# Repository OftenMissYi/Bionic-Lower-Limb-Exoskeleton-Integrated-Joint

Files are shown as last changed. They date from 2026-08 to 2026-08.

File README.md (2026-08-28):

# 🦿 Bionic Lower-Limb Exoskeleton Integrated Joint

Design and performance analysis of an integrated joint drive unit for a bionic lower-limb exoskeleton, developed as my undergraduate graduation project.

The project focused on the mechanical design and integration of a compact knee joint actuator, combining a high-power-density BLDC motor, planetary gearbox and torque sensing into an integrated drive unit. The designed actuator was also integrated into an existing lower-limb exoskeleton structure through an in-situ replacement approach.

## 🔧 Key Contributions

* Designed an integrated knee joint drive unit for a bionic lower-limb exoskeleton
* Developed a single-stage NGW planetary gearbox with a reduction ratio of 3.75
* Performed motor selection and transmission parameter design
* Designed the integrated mechanical structure, including the housing, shaft system, output interface and supporting components
* Integrated a torque sensor into the drive transmission chain
* Designed the drive unit for direct integration with an existing exoskeleton structure
* Performed structural and performance analysis using finite element and multibody dynamics simulation
* Evaluated stress, deformation, output speed, motor torque and transmission error under rated and peak load conditions
* Proposed a hierarchical control architecture combining gait-phase recognition, impedance control and ADRC-based trajectory tracking

## ⚙️ Design Overview

The actuator follows a quasi-direct-drive (QDD) concept based on a high-power-density BLDC motor and a compact planetary gearbox.

The main design targets included:

* Peak output torque: ≥ 55 N·m
* Rated output torque: 21 N·m
* Joint operating range: 0–160°
* Planetary gearbox ratio: 3.75
* Target transmission efficiency: ≥ 90%

The integrated design combines the drive, transmission and torque sensing functions into a compact coaxial mechanical system.

## 🧮 Simulation & Analysis

The designed drive unit was evaluated through both finite element analysis and multibody dynamics simulation.

### Finite Element Analysis

Structural simulations were used to evaluate the planetary gearbox and integrated mechanical structure under representative loading conditions, including stress, strain and deformation.

### ADAMS Multibody Dynamics

A multibody dynamics model was developed to evaluate the dynamic behaviour of the planetary transmission under changing load conditions.

The analysis included:

* Output angular velocity
* Motor driving torque
* Gear meshing forces
* Transmission error
* Dynamic response under rated and peak torque loading

The simulation results were used to verify the feasibility of the mechanical design and its ability to meet the target performance requirements.

## 🧠 Control Strategy

A hierarchical control concept was developed for the integrated joint drive system, consisting of gait-phase recognition, dual-mode control and low-level motor control.

The proposed strategy combines adaptive impedance control during the support phase with ADRC-based trajectory tracking during the swing phase.

The control architecture was developed at the theoretical/software level as part of the project. Physical prototype and hardware-in-the-loop validation were outside the completed project scope.

## 📁 Repository Structure

```text
Bionic-Lower-Limb-Exoskeleton/
├── CAD/
│   ├── Drive_Unit/
│   ├── Planetary_Gearbox/
│   └── Exoskeleton_Integration/
│
├── Simulation/
│   ├── ANSYS/
│   └── ADAMS/
│
└── docs/
    ├── project_report_excerpt.pdf
    └── defense_presentation.pdf
```

The repository contains the original CAD and simulation project files together with selected documentation from the undergraduate thesis and defense presentation.

Some CAD and simulation files retain their original Chinese filenames and may require the corresponding commercial software to open.

## 🛠️ Technologies

`SolidWorks` · `ANSYS Workbench` · `MSC Adams` · `Planetary Gearbox` · `Mechanical Design` · `Finite Element Analysis` · `Multibody Dynamics` · `Robot Actuation`

## ⚠️ Project Scope & Limitations

This project focused primarily on the mechanical design, integration and simulation-based evaluation of a single knee joint drive unit.

The project did not include:

* Physical prototype fabrication
* Experimental validation on a wearable exoskeleton
* Hardware-in-the-loop testing
* Multi-joint gait experiments

The repository therefore represents the engineering design and simulation stage of the project rather than a fully experimentally validated exoskeleton system.

## 📚 Documentation

Selected pages from the original undergraduate thesis are provided in `docs/` together with the complete defense presentation for additional technical background and design details.

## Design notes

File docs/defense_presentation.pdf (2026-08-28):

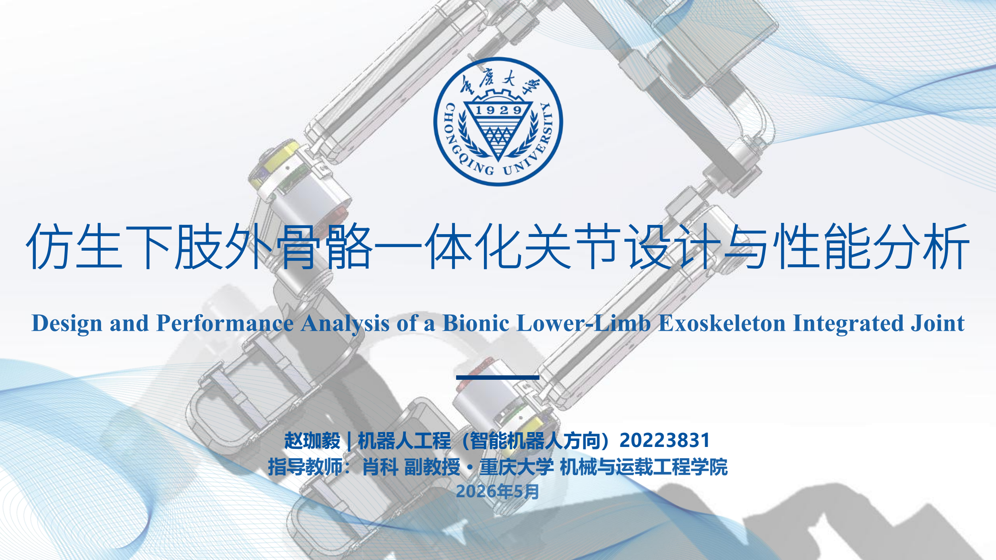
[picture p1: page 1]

# 仿生下肢外骨骼一体化关节设计与性能分析

# Design and Performance Analysis of a Bionic Lower-Limb Exoskeleton Integrated Joint

## 赵珈毅 | 机器人工程（智能机器人方向）20223831 指导教师：肖科 副教授 · 重庆大学 机械与运载工程学院

2026年5月

# 汇报提纲

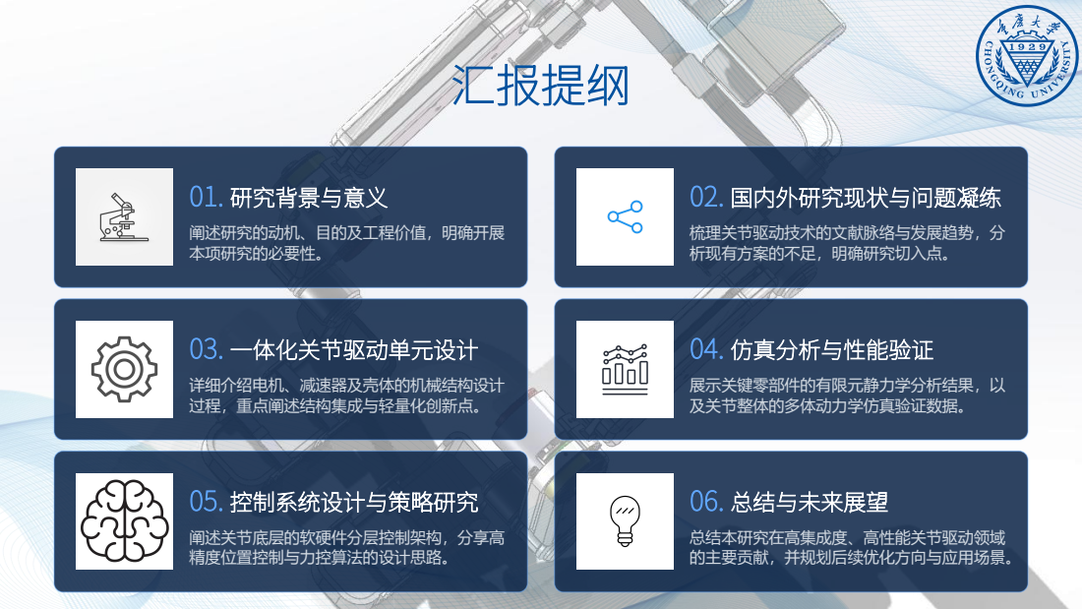
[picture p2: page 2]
01. 研究背景与意义; 02. 国内外研究现状与问题凝练; 梳理关节驱动技术的文献脉络与发展趋势，分 析现有方案的不足，明确研究切入点。; 详细介绍电机、减速器及壳体的机械结构设计 过程，重点阐述结构集成与轻量化创新点。; 04. 仿真分析与性能验证; 展示关键零部件的有限元静力学分析结果，以 及关节整体的多体动力学仿真验证数据。; 05. 控制系统设计与策略研究; 阐述关节底层的软硬件分层控制架构，分享高 精度位置控制与力控算法的设计思路。; 06. 总结与未来展望; 总结本研究在高集成度、高性能关节驱动领域 的主要贡献，并规划后续优化方向与应用场景。

阐述研究的动机、目的及工程价值，明确开展
本项研究的必要性。
03. 一体化关节驱动单元设计

# 研究背景与意义 —— 问题的提出

# 为什么要设计一体化关节驱动器？

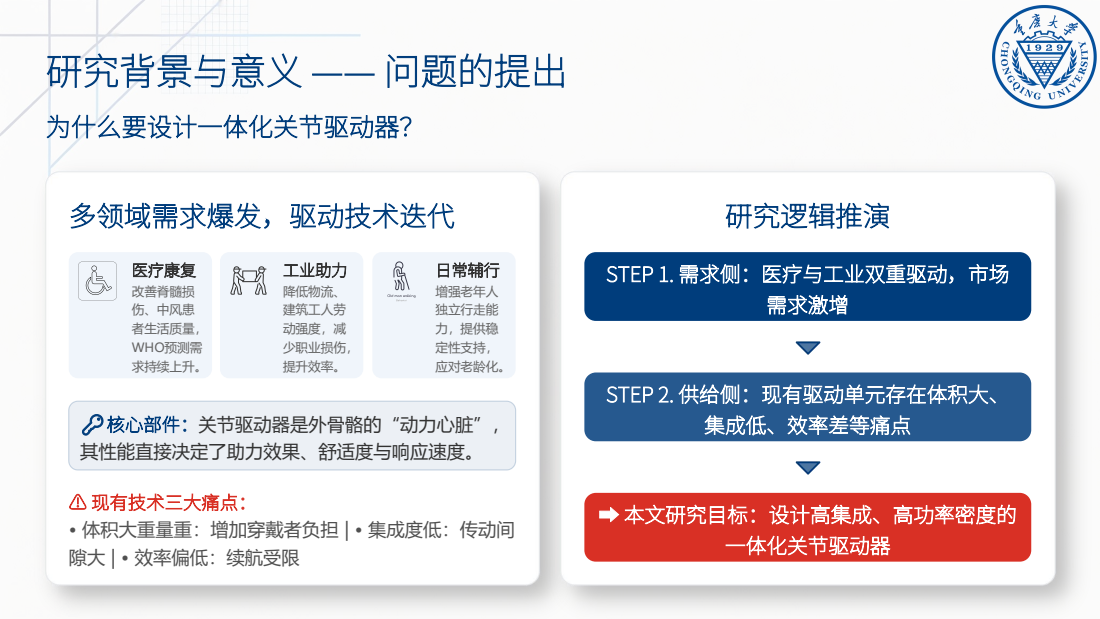
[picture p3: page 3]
多领域需求爆发，驱动技术迭代; 医疗康复; 求持续上升。; 工业助力; 降低物流、 建筑工人劳 动强度，减 少职业损伤，; 提升效率。; 日常辅行; 增强老年人 独立行走能 力，提供稳 定性支持，

研究逻辑推演
STEP 1. 需求侧：医疗与工业双重驱动，市场
需求激增
STEP 2. 供给侧：现有驱动单元存在体积大、
集成低、效率差等痛点
➡ 本文研究目标：设计高集成、高功率密度的
一体化关节驱动器

改善脊髓损
伤、中风患
者生活质量， WHO预测需
应对老龄化。  核心部件：关节驱动器是外骨骼的“动力心脏”，

其性能直接决定了助力效果、舒适度与响应速度。
⚠ 现有技术三大痛点：
• 体积大重量重：增加穿戴者负担 | • 集成度低：传动间
隙大 | • 效率偏低：续航受限

# 研究背景与意义 —— 研究目标与工程价值

## 核心目标：提出并设计一种“驱动-传动-检测”一体化、高功率密度的仿生下肢

## 外骨骼膝关节驱动器，旨在解决现有驱动单元体积大、集成度低、效率不高等关 键问题，为外骨骼系统的性能提升提供核心动力方案。

# ▍ 工程价值

- 准直接驱动 (QDD) 架构：采用“无刷直流电机 + 单级
行星减速器”的复合方案，兼顾输出大扭矩、高传动效率和良 好的背驱特性。
- 力矩传感器内嵌集成：将多维力矩传感器深度融合进传 动链，实现“驱动-传动-检测”一体化闭环控制，显著提升系 统的控制精度与动态响应速度。
- 原位替换设计：标准化机械与电气接口设计，可直接集成
到现有主流外骨骼骨架中，具备极强的工程通用性。 | ▍ 应用前景
| · 医疗康复领域：可应用于康复机器人，为脊髓损伤、脑卒 中患者提供高精度、高舒适度的康复训练与辅助步行。
| · 工业助力领域：适配工业外骨骼，在物流搬运、汽车制造 等体力消耗大的场景中，为工人提供有效负重助力，降低职业 损伤风险。
| · 日常辅助领域：为高龄老人或行动不便人群提供行走稳定 性支持，帮助他们独立完成日常生活活动，提升生活质量。

# 二、国内外研究现状 —— 四个维度的文献脉络

# 01 运动机理与生物力学

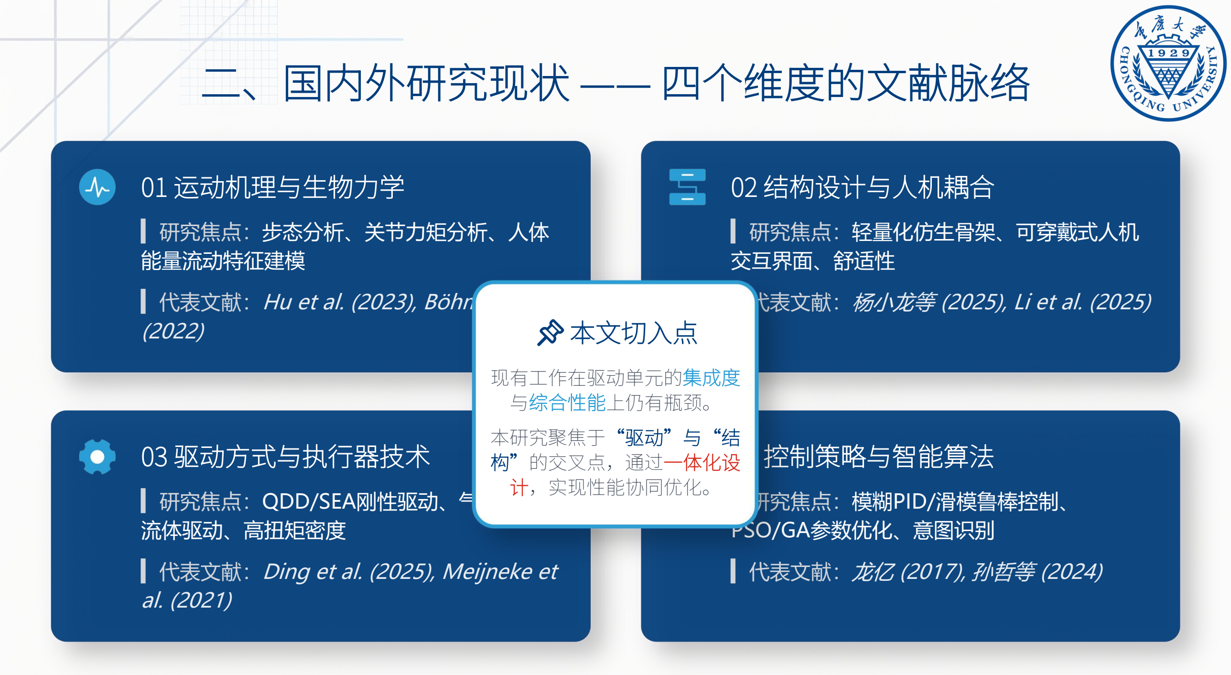
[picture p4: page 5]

▍ 研究焦点：步态分析、关节力矩分析、人体
能量流动特征建模
▍ 代表文献：Hu et al. (2023), Böhme et al. (2022)

# 02 结构设计与人机耦合

▍ 研究焦点：轻量化仿生骨架、可穿戴式人机
交互界面、舒适性
▍ 代表文献：杨小龙等 (2025), Li et al. (2025)

# 03 驱动方式与执行器技术

▍ 研究焦点：QDD/SEA刚性驱动、气动/柔性
流体驱动、高扭矩密度
▍ 代表文献：Ding et al. (2025), Meijneke et al. (2021)

# 04 控制策略与智能算法

▍ 研究焦点：模糊PID/滑模鲁棒控制、
PSO/GA参数优化、意图识别
▍ 代表文献：龙亿 (2017), 孙哲等 (2024)

# 本文切入点

# 现有工作在驱动单元的集成度 与综合性能上仍有瓶颈。 本研究聚焦于“驱动”与“结 构”的交叉点，通过一体化设 计，实现性能协同优化。

# 二、国内外研究现状 —— 问题凝练与本文定位

驱动方式 | 输出扭矩 | 体积 / 重量 | 背驱性 | 集成度 | 适用场景
电机直驱 | 小 | 小 | 极好 | 极高 | 低负载、高响应关节
丝杠驱动 | 大 | 大 | 差 | 低 | 高负载、低速、固定场景
谐波减速 | 大 | 中 | 差 | 中 | 工业机器人、高精度定位
行星齿轮 (QDD) | 中 - 大 | 小 | 好 | 高 | ← 本文选择 一体化集成

将电机、减速器、传感器进行同轴一体化
设计，在保证功能完备性的同时最大化空
间利用率，提升系统整体紧凑性。 | 准直接驱动

采用行星齿轮减速器(QDD)方案，在大扭
矩输出与良好背驱性之间取得最佳平衡，
满足动态响应与负载能力的双重需求。 | 分层控制策略

设计包含“模式识别层-双模态切换层-底
层伺服控制层”的三层架构，实现从高层
意图到底层执行的精准、稳定映射。

# 二、国内外研究现状 —— 问题凝练与本文定位

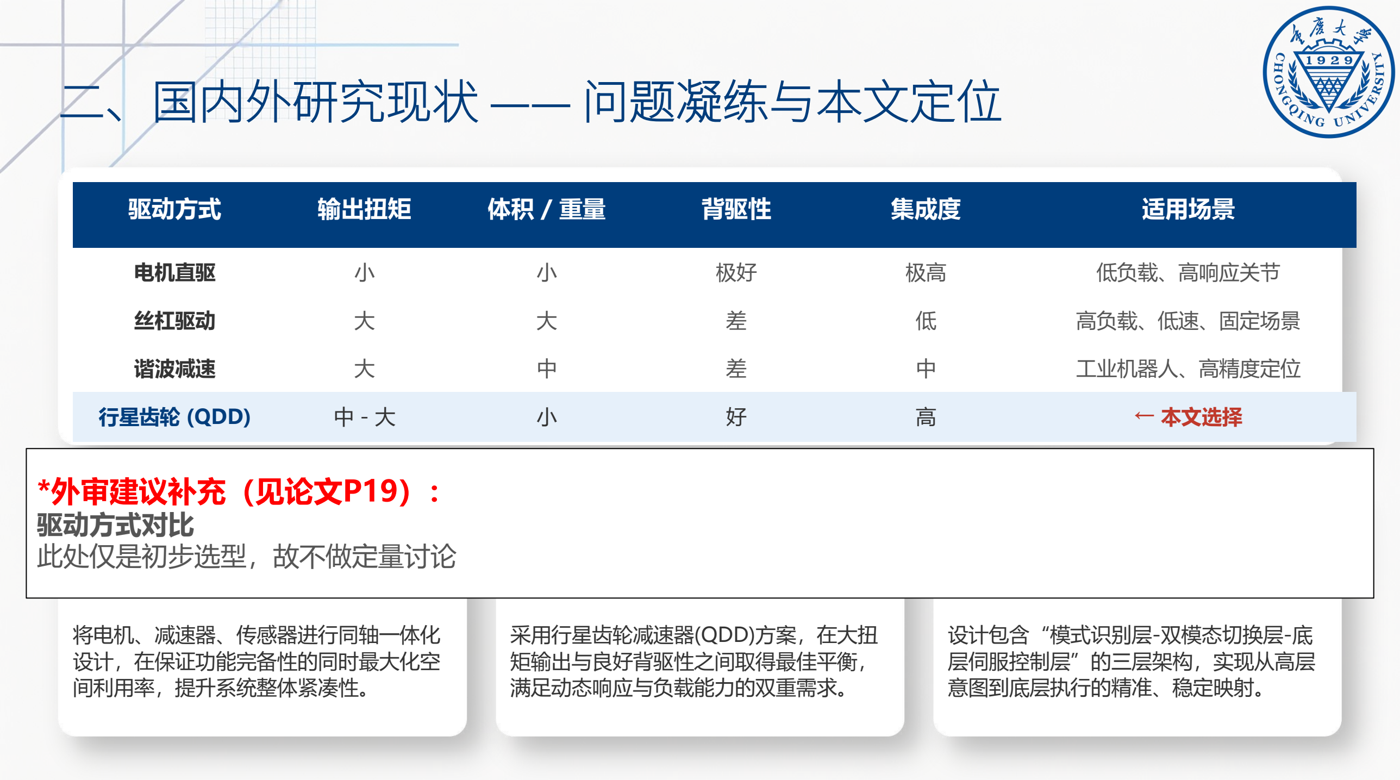
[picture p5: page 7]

驱动方式 | 输出扭矩 | 体积 / 重量 | 背驱性 | 集成度 | 适用场景
电机直驱 | 小 | 小 | 极好 | 极高 | 低负载、高响应关节
丝杠驱动 | 大 | 大 | 差 | 低 | 高负载、低速、固定场景
谐波减速 | 大 | 中 | 差 | 中 | 工业机器人、高精度定位
行星齿轮 (QDD) | 中 - 大 | 小 | 好 | 高 | ← 本文选择 一体化集成

将电机、减速器、传感器进行同轴一体化
设计，在保证功能完备性的同时最大化空
间利用率，提升系统整体紧凑性。 | 准直接驱动

采用行星齿轮减速器(QDD)方案，在大扭
矩输出与良好背驱性之间取得最佳平衡，
满足动态响应与负载能力的双重需求。 | 分层控制策略

设计包含“模式识别层-双模态切换层-底
层伺服控制层”的三层架构，实现从高层
意图到底层执行的精准、稳定映射。

## *外审建议补充（见论文P19）：

## 驱动方式对比

### 此处仅是初步选型，故不做定量讨论

# 三、一体化关节设计 —— 人体步态与设计指标

# ▌ 人体步态周期关键信息

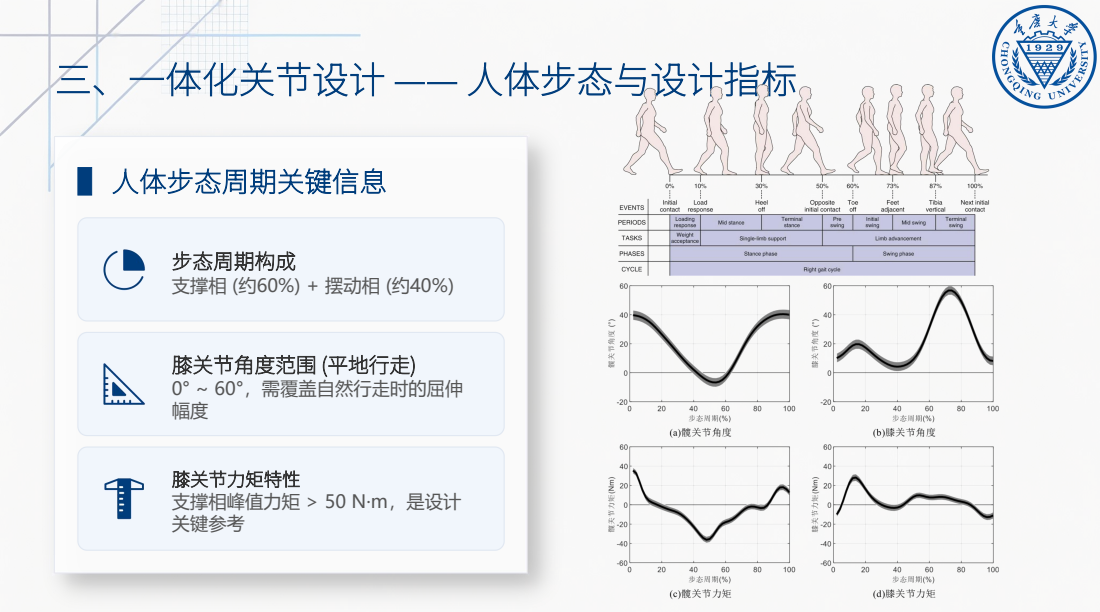
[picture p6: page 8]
步态周期构成; 支撑相 (约60%) + 摆动相 (约40%) 膝关节角度范围 (平地行走); 0° ~ 60°，需覆盖自然行走时的屈伸 幅度 膝关节力矩特性; 支撑相峰值力矩 > 50 N·m，是设计 关键参考

# 三、一体化关节设计 —— 人体步态与设计指标

# ▌ 膝关节驱动单元设计指标

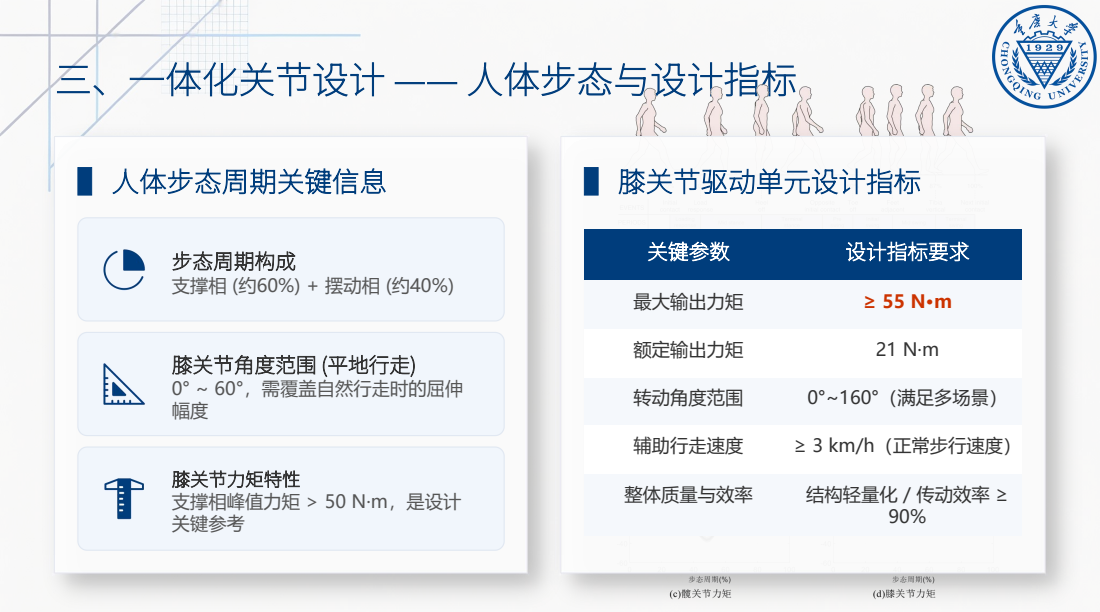
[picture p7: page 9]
▌ 人体步态周期关键信息; 步态周期构成; 支撑相 (约60%) + 摆动相 (约40%) 膝关节角度范围 (平地行走); 0° ~ 60°，需覆盖自然行走时的屈伸 幅度 膝关节力矩特性; 支撑相峰值力矩 > 50 N·m，是设计 关键参考

关键参数 | 设计指标要求

最大输出力矩 | ≥ 55 N·m

额定输出力矩 | 21 N·m

转动角度范围 | 0°~160°（满足多场景）

辅助行走速度 | ≥ 3 km/h（正常步行速度）

整体质量与效率 | 结构轻量化 / 传动效率 ≥ 90%

# 三、一体化关节设计 —— 总体方案与驱动选型

# 总体架构：准直接驱动 (QDD) 理念

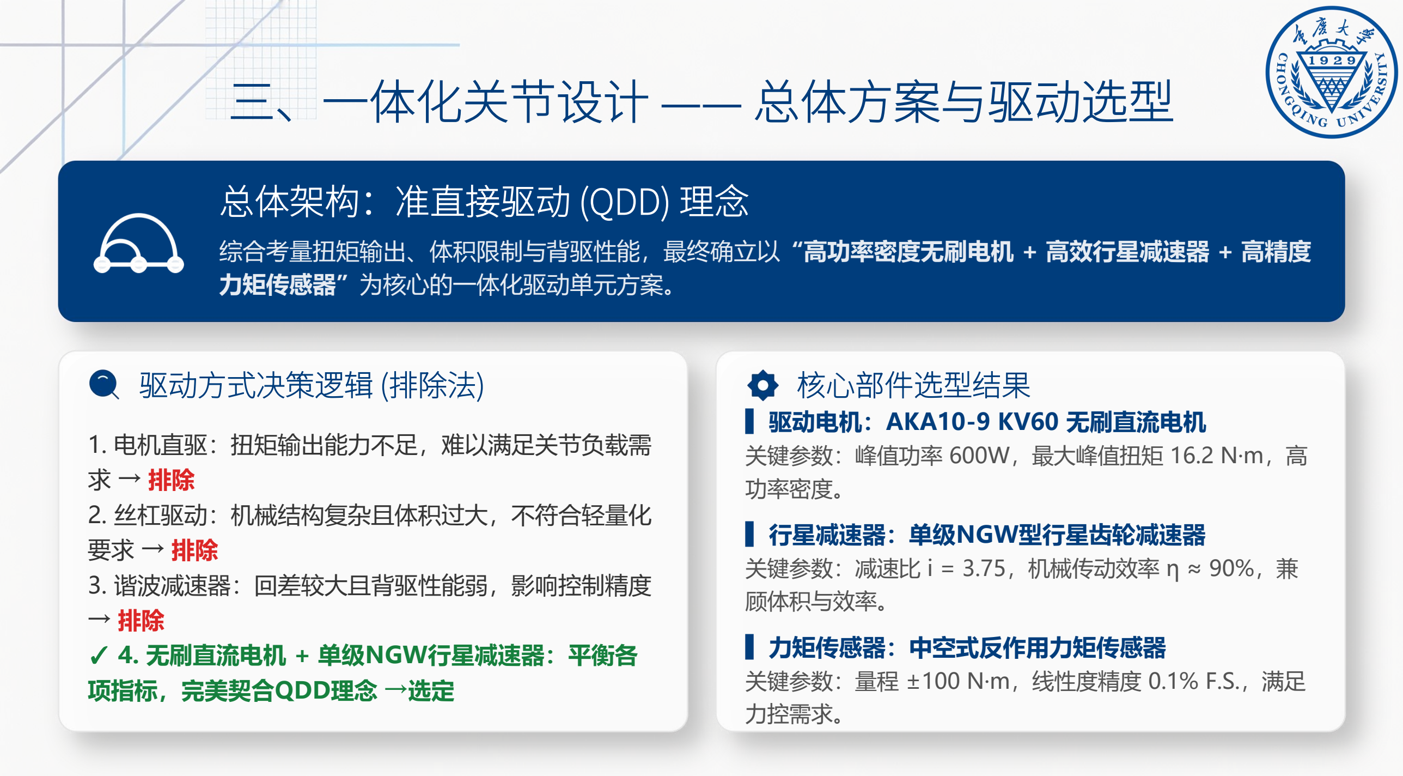
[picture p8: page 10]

综合考量扭矩输出、体积限制与背驱性能，最终确立以“高功率密度无刷电机 + 高效行星减速器 + 高精度 力矩传感器”为核心的一体化驱动单元方案。 驱动方式决策逻辑 (排除法)

1. 电机直驱：扭矩输出能力不足，难以满足关节负载需 求 → 排除
2. 丝杠驱动：机械结构复杂且体积过大，不符合轻量化 要求 → 排除
3. 谐波减速器：回差较大且背驱性能弱，影响控制精度 → 排除
✓ 4. 无刷直流电机 + 单级NGW行星减速器：平衡各 项指标，完美契合QDD理念 →选定

# 核心部件选型结果

▌ 驱动电机：AKA10-9 KV60 无刷直流电机 关键参数：峰值功率 600W，最大峰值扭矩 16.2 N·m，高 功率密度。
▌ 行星减速器：单级NGW型行星齿轮减速器
关键参数：减速比 i = 3.75，机械传动效率 η ≈ 90%，兼 顾体积与效率。
▌ 力矩传感器：中空式反作用力矩传感器
关键参数：量程 ±100 N·m，线性度精度 0.1% F.S.，满足 力控需求。

# 三、一体化关节设计 —— 总体方案与驱动选型

# 总体架构：准直接驱动 (QDD) 理念

综合考量扭矩输出、体积限制与背驱性能，最终确立以“高功率密度无刷电机 + 高效行星减速器 + 高精度 力矩传感器”为核心的一体化驱动单元方案。 驱动方式决策逻辑 (排除法)

1. 电机直驱：扭矩输出能力不足，难以满足关节负载需 求 → 排除
2. 丝杠驱动：机械结构复杂且体积过大，不符合轻量化 要求 → 排除
3. 谐波减速器：回差较大且背驱性能弱，影响控制精度 → 排除
✓ 4. 无刷直流电机 + 单级NGW行星减速器：平衡各 项指标，完美契合QDD理念 →选定

# 核心部件选型结果

▌ 驱动电机：AKA10-9 KV60 无刷直流电机 关键参数：峰值功率 600W，最大峰值扭矩 16.2 N·m，高 功率密度。
▌ 行星减速器：单级NGW型行星齿轮减速器
关键参数：减速比 i = 3.75，机械传动效率 η ≈ 90%，兼 顾体积与效率。
▌ 力矩传感器：中空式反作用力矩传感器
关键参数：量程 ±100 N·m，线性度精度 0.1% F.S.，满足 力控需求。

# 三、一体化关节设计 —— 行星减速器核心参数

齿根弯曲应力 <200 MPa ✓ 强度安全

# 三、一体化关节设计 —— 行星减速器核心参数

## *外审建议补充（见论文P23）：

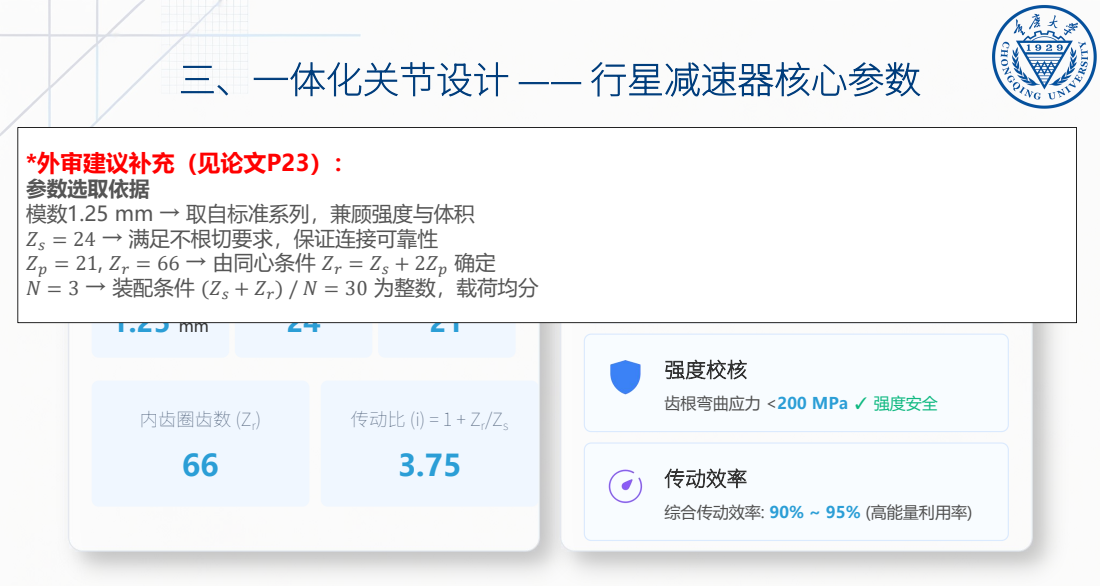
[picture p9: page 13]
核心设计参数; 太阳轮齿数 (Zs) 24; 行星轮齿数 (Zp; 内齿圈齿数 (Zr) 66; 传动比 (i) = 1 + Zr/Zs 3.75; 性能校核 理论输出扭矩; ≈60.75 N·m (目标: 55 N·m) ✓ 满足要求 强度校核; 传动效率; 综合传动效率: 90% ~ 95% (高能量利用率);  = 21,  = 66 → 由同心条件  =  + 2 确定  = 3 → 装配条件 ( + ) /  = 30 为整数，载荷均分

参数选取依据
 = 24 → 满足不根切要求，保证连接可靠性
模数1.25 mm → 取自标准系列，兼顾强度与体积

齿根弯曲应力 <200 MPa ✓ 强度安全

# 三、一体化关节设计 —— 行星减速器核心参数

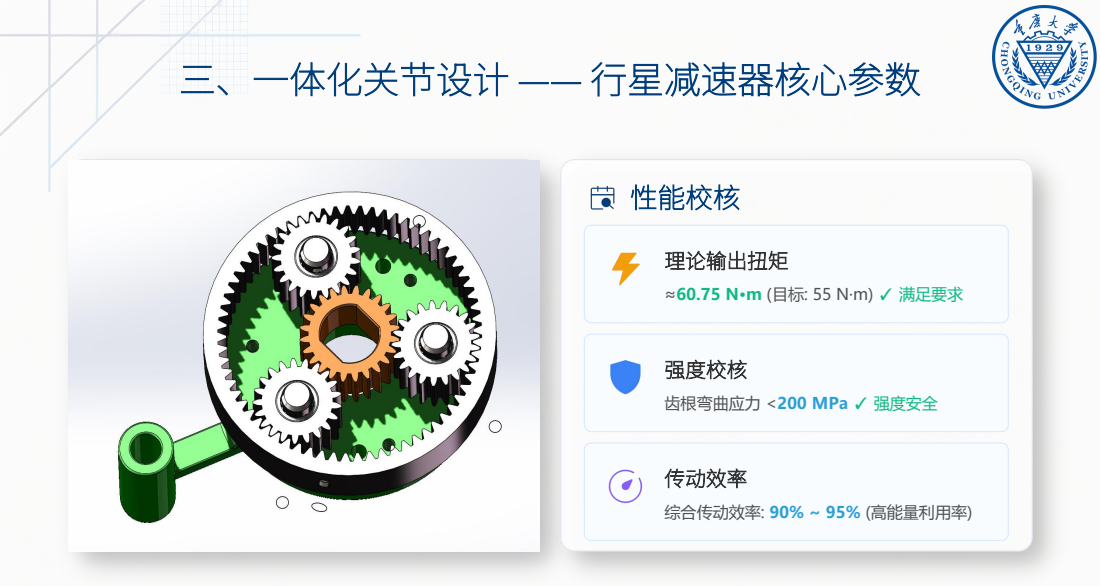
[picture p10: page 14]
核心设计参数; 太阳轮齿数 (Zs) 24; 行星轮齿数 (Zp) 21; 内齿圈齿数 (Zr) 66; 传动比 (i) = 1 + Zr/Zs 3.75; 性能校核 理论输出扭矩; ≈60.75 N·m (目标: 55 N·m) ✓ 满足要求 强度校核; 传动效率; 综合传动效率: 90% ~ 95% (高能量利用率)

齿根弯曲应力 <200 MPa ✓ 强度安全

# 三、一体化关节设计 —— 一体化结构创新

# 01. 一体化长轴设计

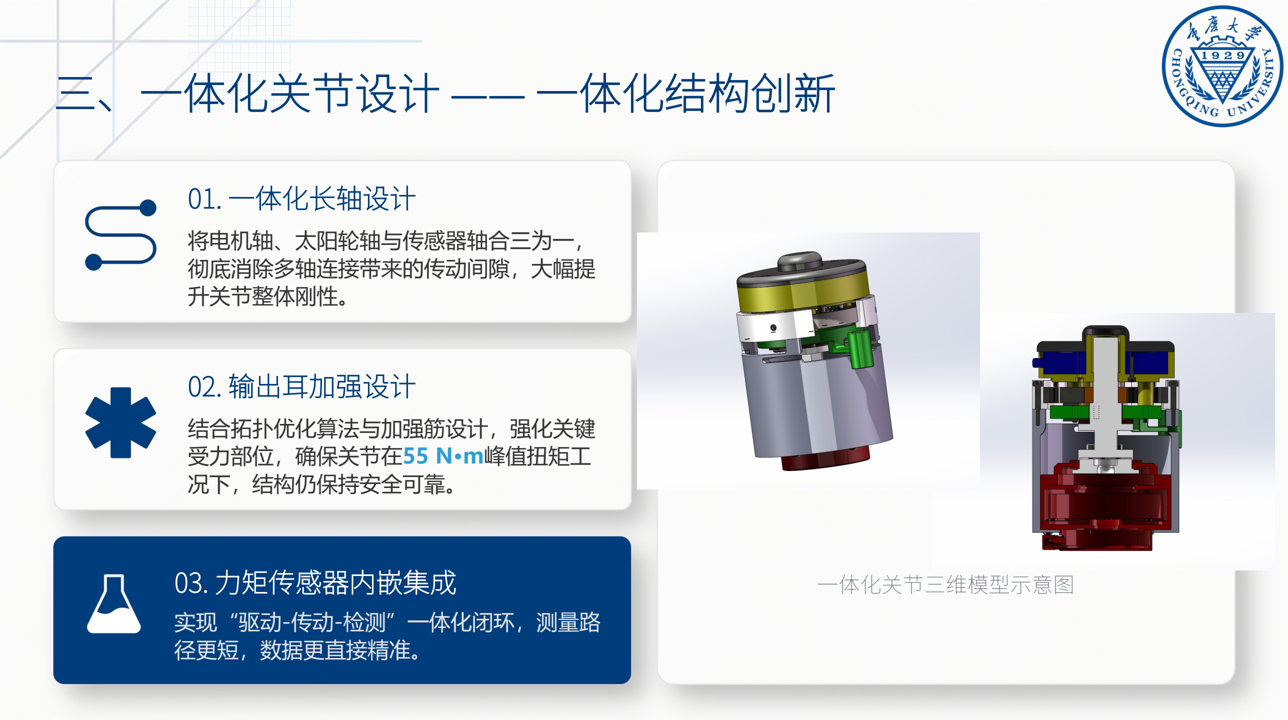
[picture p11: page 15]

将电机轴、太阳轮轴与传感器轴合三为一，
彻底消除多轴连接带来的传动间隙，大幅提
升关节整体刚性。

# 02. 输出耳加强设计

结合拓扑优化算法与加强筋设计，强化关键
受力部位，确保关节在55 N·m峰值扭矩工
况下，结构仍保持安全可靠。

# 03. 力矩传感器内嵌集成

实现“驱动-传动-检测”一体化闭环，测量路
径更短，数据更直接精准。

# 一体化关节三维模型示意图

# 四、仿真分析 —— 有限元应力与变形

# 齿面接触应力分析

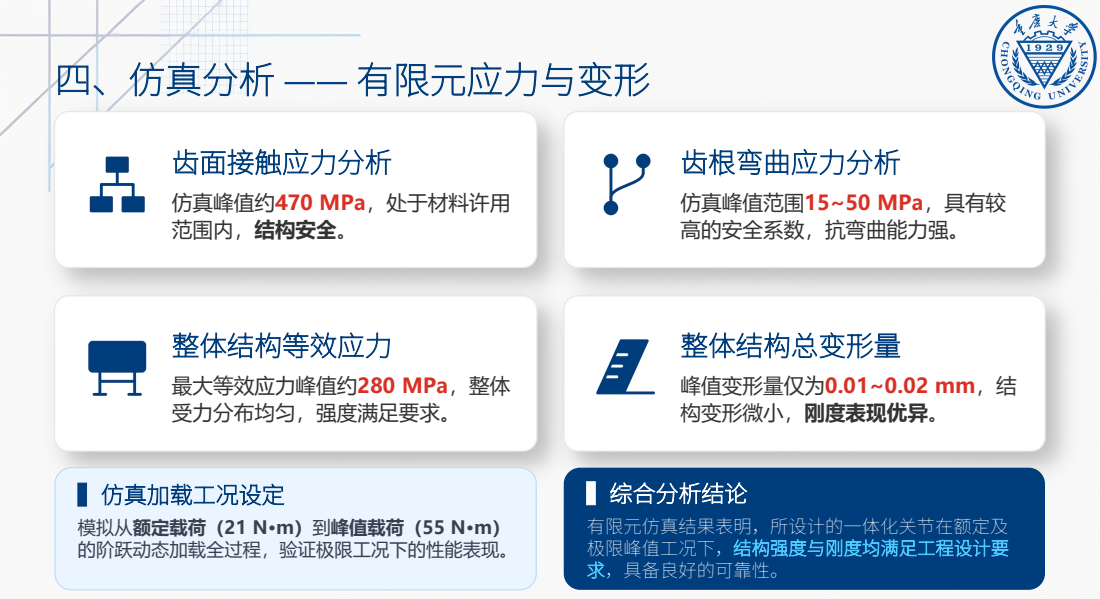
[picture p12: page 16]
范围内，结构安全。; 齿根弯曲应力分析; 仿真峰值范围15~50 MPa，具有较; 最大等效应力峰值约280 MPa，整体; 受力分布均匀，强度满足要求。; 整体结构总变形量; 峰值变形量仅为0.01~0.02 mm，结; 模拟从额定载荷（21 N·m）到峰值载荷（55 N·m）; 的阶跃动态加载全过程，验证极限工况下的性能表现。; ▍综合分析结论; 有限元仿真结果表明，所设计的一体化关节在额定及 极限峰值工况下，结构强度与刚度均满足工程设计要 求，具备良好的可靠性。

仿真峰值约470 MPa，处于材料许用
高的安全系数，抗弯曲能力强。 整体结构等效应力

构变形微小，刚度表现优异。 ▍仿真加载工况设定

# 四、仿真分析 —— 有限元应力与变形

# 齿面接触应力分析

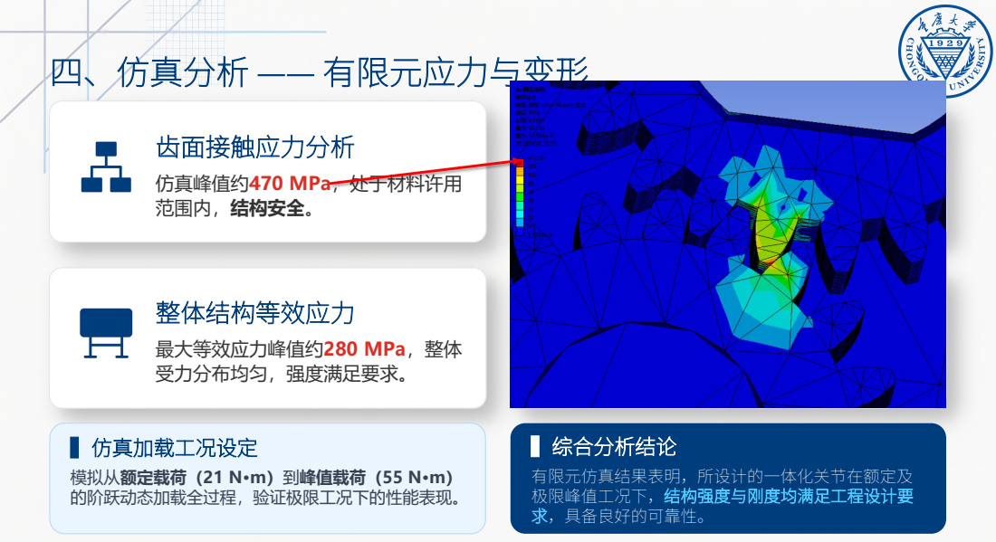
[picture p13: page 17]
范围内，结构安全。; 齿根弯曲应力分析; 仿真峰值范围15~50 MPa，具有较; 最大等效应力峰值约280 MPa，整体; 受力分布均匀，强度满足要求。; 整体结构总变形量; 峰值变形量仅为0.01~0.02 mm，结; 模拟从额定载荷（21 N·m）到峰值载荷（55 N·m）; 的阶跃动态加载全过程，验证极限工况下的性能表现。; ▍综合分析结论; 有限元仿真结果表明，所设计的一体化关节在额定及 极限峰值工况下，结构强度与刚度均满足工程设计要 求，具备良好的可靠性。

仿真峰值约470 MPa，处于材料许用
高的安全系数，抗弯曲能力强。 整体结构等效应力

构变形微小，刚度表现优异。 ▍仿真加载工况设定

# 四、仿真分析 —— 有限元应力与变形

# 齿面接触应力分析

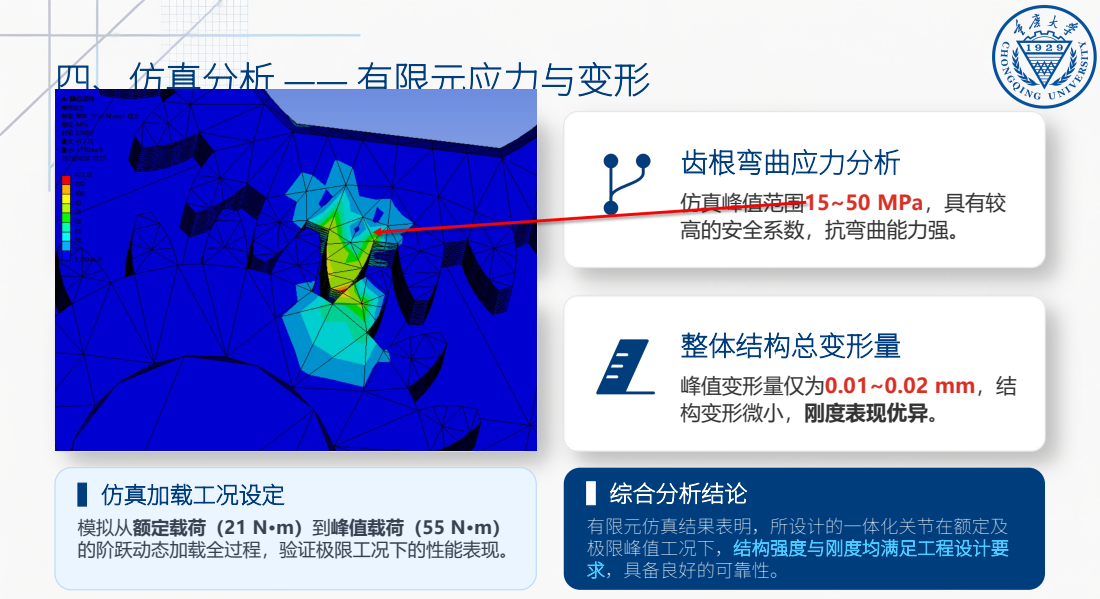
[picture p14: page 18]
范围内，结构安全。; 齿根弯曲应力分析; 仿真峰值范围15~50 MPa，具有较; 最大等效应力峰值约280 MPa，整体; 受力分布均匀，强度满足要求。; 整体结构总变形量; 峰值变形量仅为0.01~0.02 mm，结; 模拟从额定载荷（21 N·m）到峰值载荷（55 N·m）; 的阶跃动态加载全过程，验证极限工况下的性能表现。; ▍综合分析结论; 有限元仿真结果表明，所设计的一体化关节在额定及 极限峰值工况下，结构强度与刚度均满足工程设计要 求，具备良好的可靠性。

仿真峰值约470 MPa，处于材料许用
高的安全系数，抗弯曲能力强。 整体结构等效应力

构变形微小，刚度表现优异。 ▍仿真加载工况设定

# 四、仿真分析 —— 有限元应力与变形

# 齿面接触应力分析

仿真峰值约470 MPa，处于材料许用
高的安全系数，抗弯曲能力强。 最大弹性应变分析

构变形微小，刚度表现优异。 ▍仿真加载工况设定

# 四、仿真分析 —— 有限元应力与变形

# 齿面接触应力分析

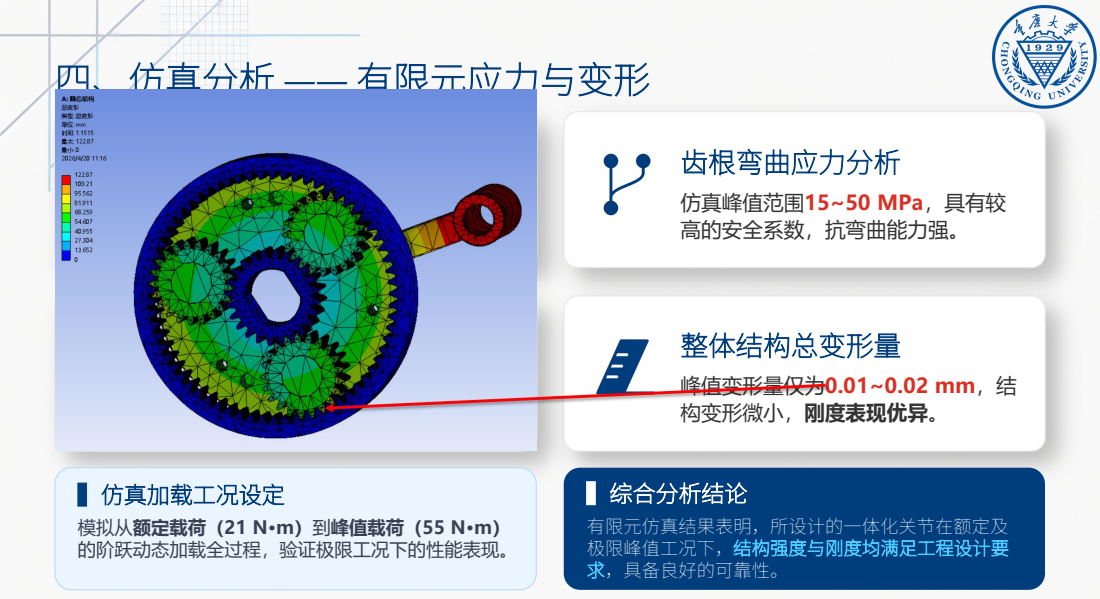
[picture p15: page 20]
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

仿真峰值约470 MPa，处于材料许用
高的安全系数，抗弯曲能力强。 整体结构等效应力

构变形微小，刚度表现优异。 ▍仿真加载工况设定

# 四、仿真分析 —— ADAMS动力学仿真

# 仿真负载工况设定

### - 0~2s：负载稳定在 21 N·m | • 2~2.05s：阶跃变化，模拟突变负载 | • 2.05s后：稳定在 55 N·m 的峰值负载

# 输出角速度响应

实际响应值为174.5 deg/s， 与理论设计值高度吻合，关节

在变载下的速度保持能力优异。 | 传动误差分析
| 稳态运行阶段，传动误差严格 控制在±5 deg/s以内，充分
验证了关节设计的高传动精度。 | 电机驱动力矩响应
| 55N·m峰值负载下，电机输出 力矩约16 N·m，响应迅速且 与前期电机选型指标高度匹配。

# ADAMS仿真综合验证表明，该一体化关节设计方案具有高传动精度、快速动态响应以及稳 定的速度输出三大核心技术优势，满足设计预期。

# 四、仿真分析 —— ADAMS动力学仿真

# 仿真负载工况设定

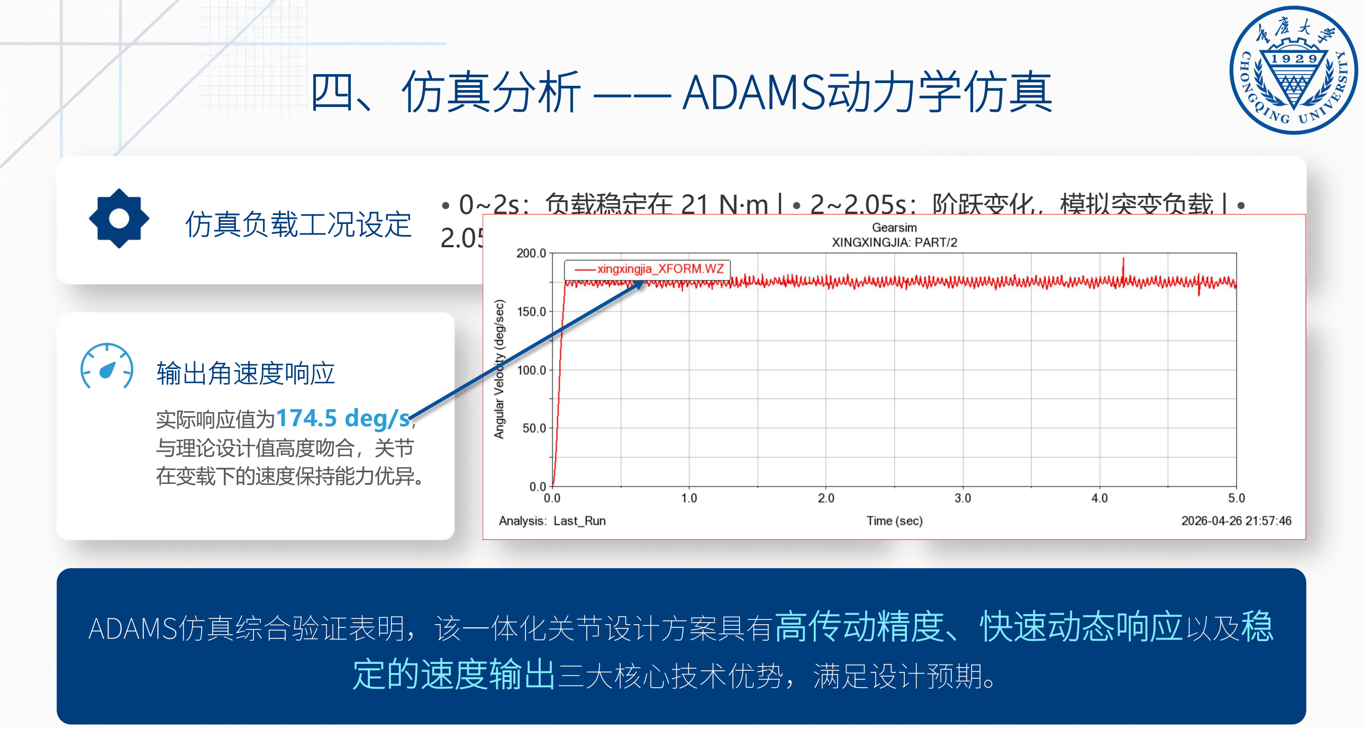
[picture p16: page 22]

### - 0~2s：负载稳定在 21 N·m | • 2~2.05s：阶跃变化，模拟突变负载 | • 2.05s后：稳定在 55 N·m 的峰值负载

# 输出角速度响应

实际响应值为174.5 deg/s， 与理论设计值高度吻合，关节

在变载下的速度保持能力优异。 | 传动误差分析
| 稳态运行阶段，传动误差严格 控制在±5 deg/s以内，充分
验证了关节设计的高传动精度。 | 电机驱动力矩响应
| 55N·m峰值负载下，电机输出 力矩约16 N·m，响应迅速且 与前期电机选型指标高度匹配。

# ADAMS仿真综合验证表明，该一体化关节设计方案具有高传动精度、快速动态响应以及稳 定的速度输出三大核心技术优势，满足设计预期。

# 四、仿真分析 —— ADAMS动力学仿真

# 仿真负载工况设定

### - 0~2s：负载稳定在 21 N·m | • 2~2.05s：阶跃变化，模拟突变负载 | • 2.05s后：稳定在 55 N·m 的峰值负载

# 输出角速度响应

实际响应值为174.5 deg/s， 与理论设计值高度吻合，关节

在变载下的速度保持能力优异。 | 传动误差分析
| 稳态运行阶段，传动误差严格 控制在±5 deg/s以内，充分
验证了关节设计的高传动精度。 | 电机驱动力矩响应
| 55N·m峰值负载下，电机输出 力矩约16 N·m，响应迅速且 与前期电机选型指标高度匹配。

# ADAMS仿真综合验证表明，该一体化关节设计方案具有高传动精度、快速动态响应以及稳 定的速度输出三大核心技术优势，满足设计预期。

# 四、仿真分析 —— ADAMS动力学仿真

# 仿真负载工况设定

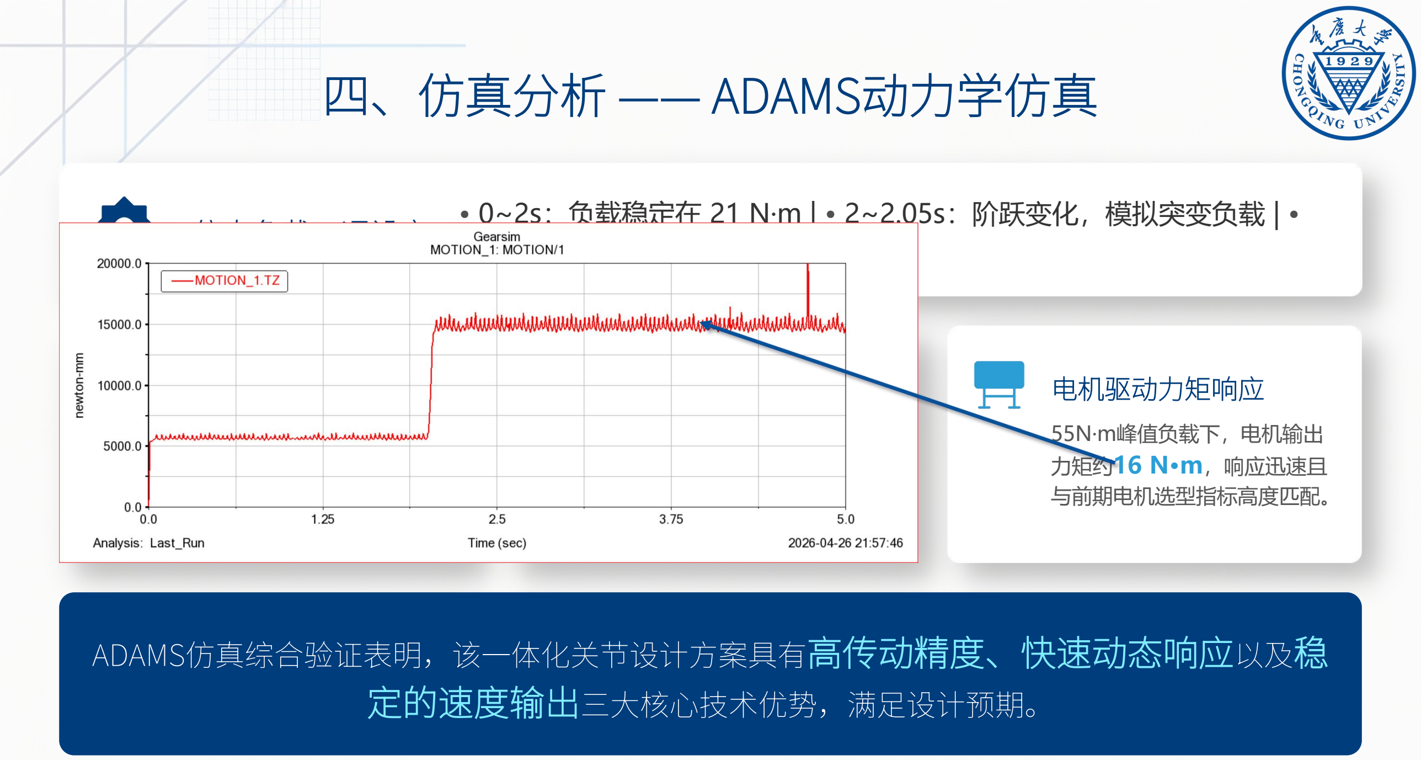
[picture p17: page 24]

### - 0~2s：负载稳定在 21 N·m | • 2~2.05s：阶跃变化，模拟突变负载 | • 2.05s后：稳定在 55 N·m 的峰值负载

# 输出角速度响应

实际响应值为174.5 deg/s， 与理论设计值高度吻合，关节

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

# ADAMS仿真综合验证表明，该一体化关节设计方案具有高传动精度、快速动态响应以及稳 定的速度输出三大核心技术优势，满足设计预期。

# 四、仿真分析 —— ADAMS动力学仿真

# 仿真负载工况设定

### - 0~2s：负载稳定在 21 N·m | • 2~2.05s：阶跃变化，模拟突变负载 | • 2.05s后：稳定在 55 N·m 的峰值负载

# 输出角速度响应

实际响应值为174.5 deg/s， 与理论设计值高度吻合，关节

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

# ADAMS仿真综合验证表明，该一体化关节设计方案具有高传动精度、快速动态响应以及稳 定的速度输出三大核心技术优势，满足设计预期。

## *外审建议补充（见论文P46）：

## 摩擦力矩折算校核

### 减速器内部摩擦分量约500 N·mm，折算到电机端： , = 500/(3.75 × 0.9) ≈ 0.15 ·，峰值工况下电机总转矩

### 约15.15 N·m，小于额定扭矩18 N·m（裕度16%），满足要求。

# 四、仿真分析 —— 结果汇总对比表

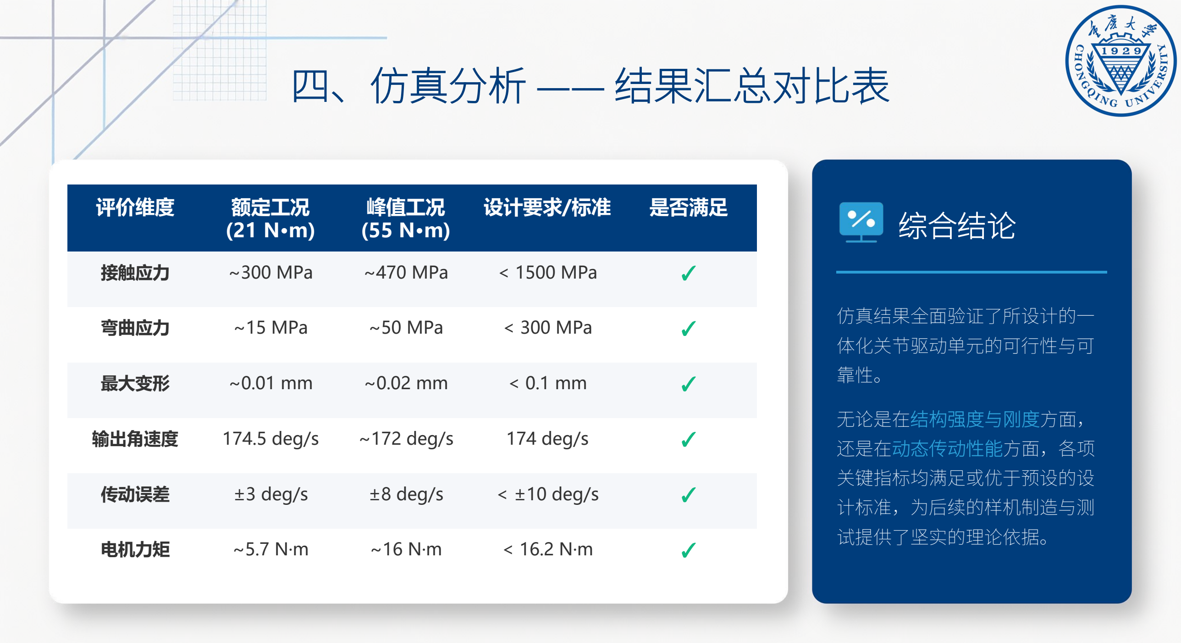
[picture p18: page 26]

评价维度 | 额定工况 (21 N·m) | 峰值工况 (55 N·m) | 设计要求/标准 | 是否满足
接触应力 | ~300 MPa | ~470 MPa | < 1500 MPa | ✓
弯曲应力 | ~15 MPa | ~50 MPa | < 300 MPa | ✓
最大变形 | ~0.01 mm | ~0.02 mm | < 0.1 mm | ✓
输出角速度 | 174.5 deg/s | ~172 deg/s | 174 deg/s | ✓
传动误差 | ±3 deg/s | ±8 deg/s | < ±10 deg/s | ✓
电机力矩 | ~5.7 N·m | ~16 N·m | < 16.2 N·m | ✓

# 综合结论

# 仿真结果全面验证了所设计的一 体化关节驱动单元的可行性与可

靠性。

# 无论是在结构强度与刚度方面， 还是在动态传动性能方面，各项 关键指标均满足或优于预设的设 计标准，为后续的样机制造与测 试提供了坚实的理论依据。

# 五、控制系统设计 —— 三层架构总览

# [顶层] 步态模式识别层

## ▍核心功能

实时感知用户的运动意图，并结合
传感器数据，精准判断当前所处的
步态阶段。

## ▍关键输出

运动模式标签 + 下肢关节期望参
考轨迹

# [中层] 双模态切换控制

层

## ▍策略切换机制

•支撑相：阻抗控制算法（目标：
柔顺支撑，适应地面不平）
•摆动相：ADRC轨迹跟踪（目标：
轨迹精度优先，提升步行流畅性）

## ▍关键输出

关节所需的实时控制力矩指令

# [底层] 电机伺服控制层

## ▍执行功能

作为控制系统的“执行器”，将上
层下发的控制指令转化为电机的实
际精确输出。

## ▍核心技术

自抗扰控制（ADRC）算法，实现
对系统内外扰动的快速抑制，保证
高精度的位置与速度跟踪。

## *外审建议补充（见论文P53）：

## 惯量匹配校核

公式： = / 2

， = /

l | 负载等效惯量 ≈ 0.15 k·2（小腿+外骨骼）
l | 折算到电机端： = 0.15 / 3.75 2 ≈ 0.0107 k·2
l | 电机转子惯量： = 1002 ·2 = 1.002 × 10 −4 k·2
l | 惯量匹配比： ≈ 106

### 结论：准直接驱动系统 λ>1 是固有特征；所选电机峰值扭矩裕度充足，ADRC可将惯量不匹配纳入“总扰动”补偿。

# 五、控制系统设计 —— 三层架构总览

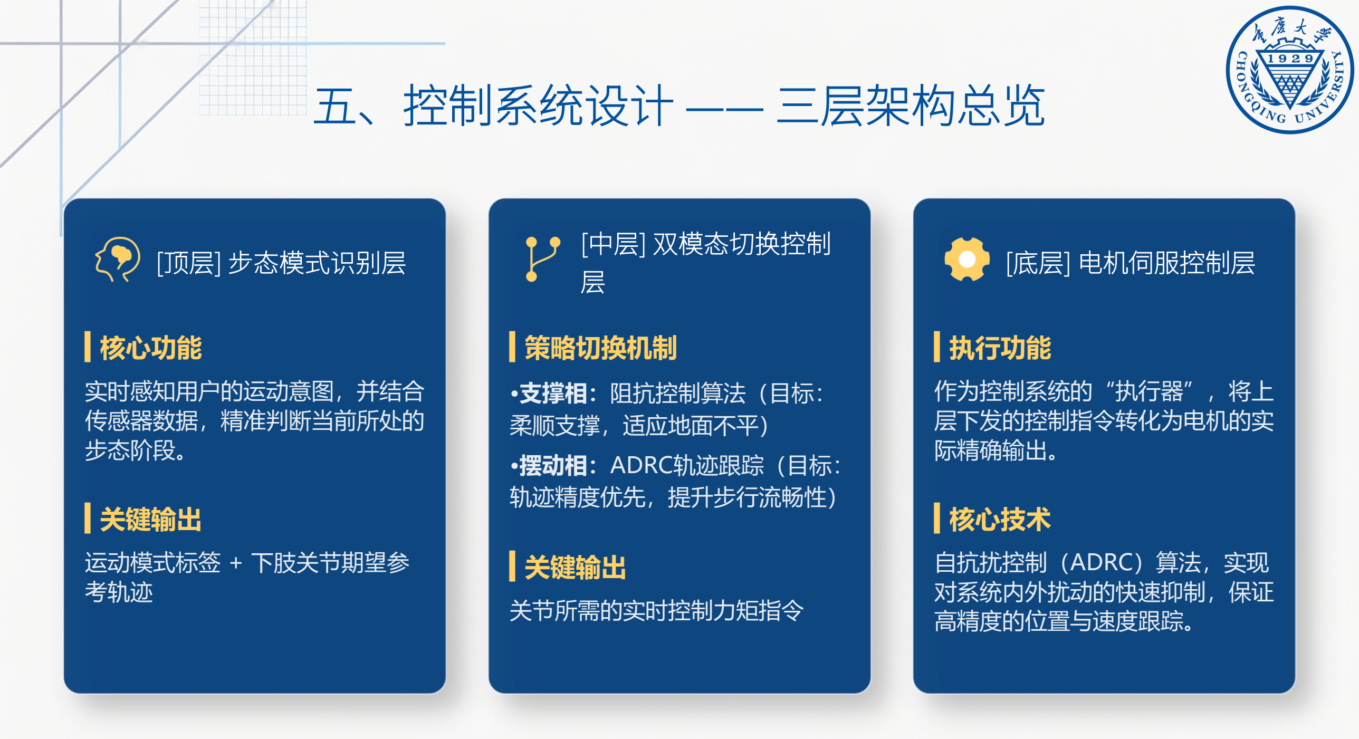
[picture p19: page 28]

# [顶层] 步态模式识别层

## ▍核心功能

实时感知用户的运动意图，并结合
传感器数据，精准判断当前所处的
步态阶段。

## ▍关键输出

运动模式标签 + 下肢关节期望参
考轨迹

# [中层] 双模态切换控制

层

## ▍策略切换机制

•支撑相：阻抗控制算法（目标：
柔顺支撑，适应地面不平）
•摆动相：ADRC轨迹跟踪（目标：
轨迹精度优先，提升步行流畅性）

## ▍关键输出

关节所需的实时控制力矩指令

# [底层] 电机伺服控制层

## ▍执行功能

作为控制系统的“执行器”，将上
层下发的控制指令转化为电机的实
际精确输出。

## ▍核心技术

自抗扰控制（ADRC）算法，实现
对系统内外扰动的快速抑制，保证
高精度的位置与速度跟踪。

# 五、控制系统设计 —— 三层架构总览

# [顶层] 步态模式识别层

## ▍核心功能

实时感知用户的运动意图，并结合
传感器数据，精准判断当前所处的
步态阶段。

## ▍关键输出

运动模式标签 + 下肢关节期望参
考轨迹

# [中层] 双模态切换控制

层

## ▍策略切换机制

•支撑相：阻抗控制算法（目标：
柔顺支撑，适应地面不平）
•摆动相：ADRC轨迹跟踪（目标：
轨迹精度优先，提升步行流畅性）

## ▍关键输出

关节所需的实时控制力矩指令

# [底层] 电机伺服控制层

## ▍执行功能

作为控制系统的“执行器”，将上
层下发的控制指令转化为电机的实
际精确输出。

## ▍核心技术

自抗扰控制（ADRC）算法，实现
对系统内外扰动的快速抑制，保证
高精度的位置与速度跟踪。

## *外审建议补充（见论文P53、P55）：

## 示意图修改

图5-1 一体化关节驱动系统分层控制架构图 | 5-2 双模态切换控制策略示意图

# 五、控制系统设计 —— 摆动相 ADRC 控制

# ▍ ADRC 核心原理架构

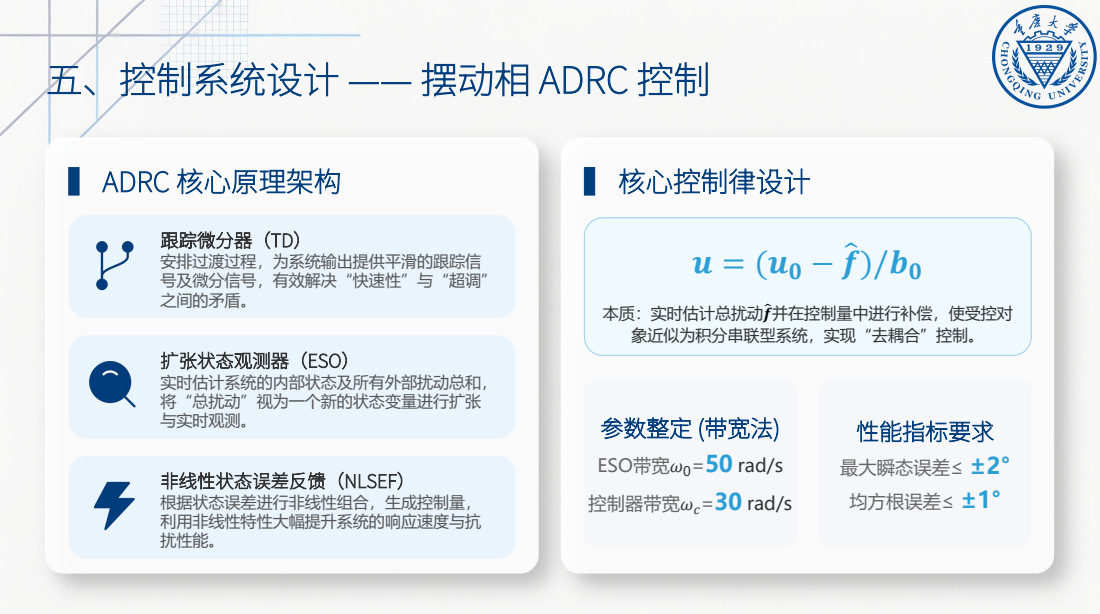
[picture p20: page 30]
根据状态误差进行非线性组合，生成控制量， 利用非线性特性大幅提升系统的响应速度与抗 扰性能。; ▍ 核心控制律设计  = ( − )/; ESO带宽0=50 rad/s; 控制器带宽; =30 rad/s; 性能指标要求; 最大瞬态误差≤ ±2° 均方根误差≤ ±1°

跟踪微分器（TD）
安排过渡过程，为系统输出提供平滑的跟踪信
号及微分信号，有效解决“快速性”与“超调”
之间的矛盾。 扩张状态观测器（ESO）

本质：实时估计总扰动并在控制量中进行补偿，使受控对

象近似为积分串联型系统，实现“去耦合”控制。 参数整定 (带宽法)

实时估计系统的内部状态及所有外部扰动总和，
将“总扰动”视为一个新的状态变量进行扩张
与实时观测。 非线性状态误差反馈（NLSEF）

# 五、控制系统设计 —— 支撑相阻抗控制与模式切换

# 支撑相控制策略：自适应阻抗控制

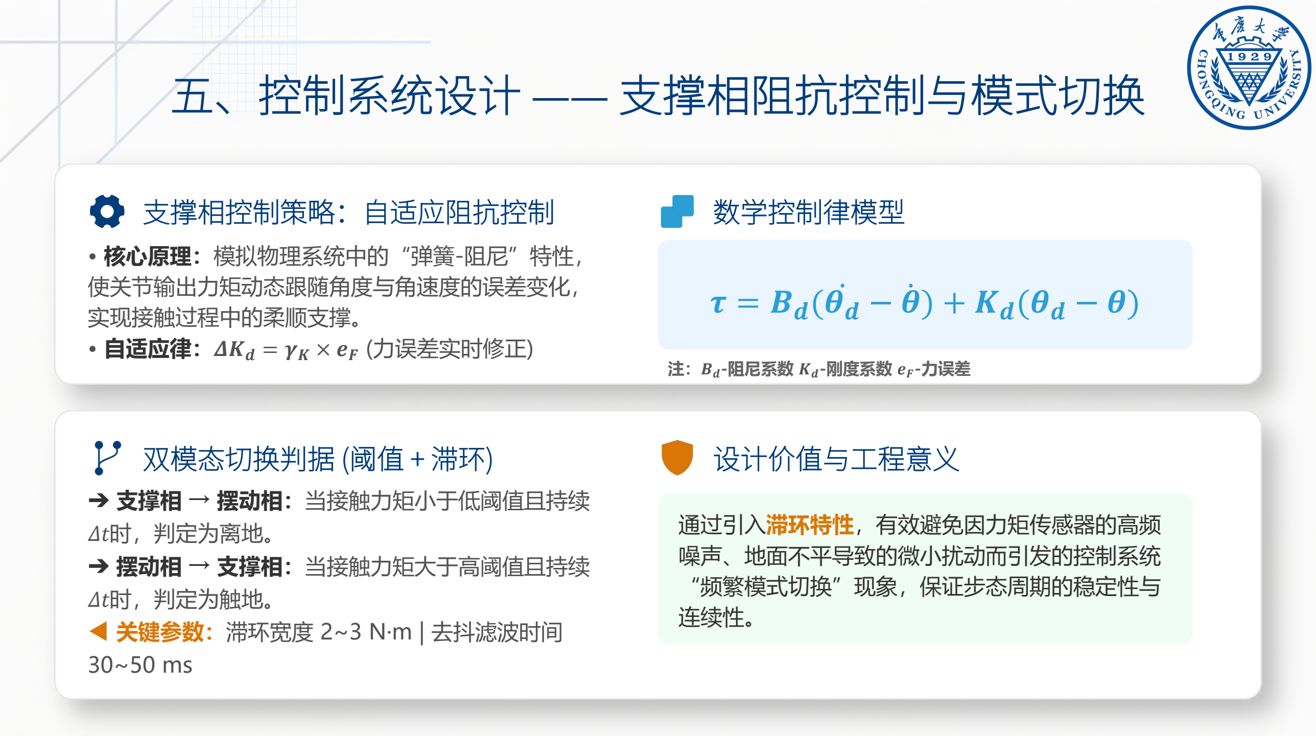
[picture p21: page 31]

- 核心原理：模拟物理系统中的“弹簧-阻尼”特性，
使关节输出力矩动态跟随角度与角速度的误差变化，
实现接触过程中的柔顺支撑。
- 自适应律： = × (力误差实时修正)

# 数学控制律模型

= ( − ) + ( − )

# 双模态切换判据 (阈值 + 滞环)

➔ 支撑相 → 摆动相：当接触力矩小于低阈值且持续

时，判定为离地。

➔ 摆动相 → 支撑相：当接触力矩大于高阈值且持续

时，判定为触地。

◀ 关键参数：滞环宽度 2~3 N·m | 去抖滤波时间
30~50 ms

# 设计价值与工程意义

通过引入滞环特性，有效避免因力矩传感器的高频
噪声、地面不平导致的微小扰动而引发的控制系统
“频繁模式切换”现象，保证步态周期的稳定性与
连续性。

注：-阻尼系数 -刚度系数 -力误差

# 五、控制系统设计 —— 支撑相阻抗控制与模式切换

# 支撑相控制策略：自适应阻抗控制

- 核心原理：模拟物理系统中的“弹簧-阻尼”特性，
使关节输出力矩动态跟随角度与角速度的误差变化，
实现接触过程中的柔顺支撑。
- 自适应律： = × (力误差实时修正)

# 数学控制律模型

= ( − ) + ( − )

# 双模态切换判据 (阈值 + 滞环)

➔ 支撑相 → 摆动相：当接触力矩小于低阈值且持续

时，判定为离地。

➔ 摆动相 → 支撑相：当接触力矩大于高阈值且持续

时，判定为触地。

◀ 关键参数：滞环宽度 2~3 N·m | 去抖滤波时间
30~50 ms

# 设计价值与工程意义

通过引入滞环特性，有效避免因力矩传感器的高频
噪声、地面不平导致的微小扰动而引发的控制系统
“频繁模式切换”现象，保证步态周期的稳定性与
连续性。

注：-阻尼系数 -刚度系数 -力误差

## *外审建议补充（见论文P60）：

## 控制策略验证不足

### 控 制 策 略 目 前 处 于 理 论 设 计 阶 段 。 性 能 评 价 指 标 的 数 据 来 源 可 通 过 两 种 途 径 获 得 ： （ 1 ） MATLAB/Simulink+ADAMS联合仿真；（2）样机实验。目前本文为后续仿真和实验提供了明确的评价标准和优 化方向。

# 六、总结与展望 —— 核心创新与贡献

# ▍ 主要贡献 Key Contributions 一体化驱动单元设计

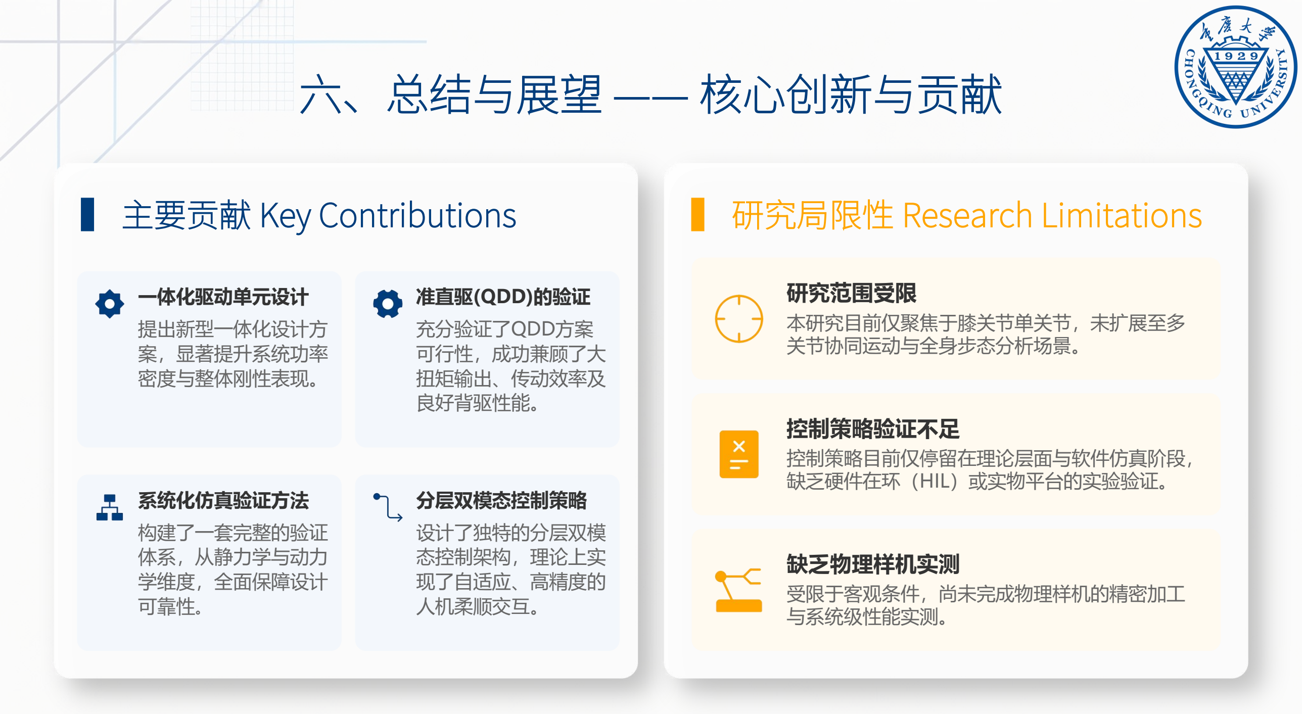
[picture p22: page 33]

提出新型一体化设计方
案，显著提升系统功率
密度与整体刚性表现。

准直驱(QDD)的验证
充分验证了QDD方案
可行性，成功兼顾了大
扭矩输出、传动效率及
良好背驱性能。

系统化仿真验证方法
构建了一套完整的验证
体系，从静力学与动力
学维度，全面保障设计
可靠性。 | 分层双模态控制策略 设计了独特的分层双模 态控制架构，理论上实 现了自适应、高精度的 人机柔顺交互。

# ▍ 研究局限性 Research Limitations

研究范围受限
本研究目前仅聚焦于膝关节单关节，未扩展至多
关节协同运动与全身步态分析场景。 控制策略验证不足

控制策略目前仅停留在理论层面与软件仿真阶段，
缺乏硬件在环（HIL）或实物平台的实验验证。 缺乏物理样机实测

受限于客观条件，尚未完成物理样机的精密加工
与系统级性能实测。

# 六、总结与展望 —— 核心创新与贡献

# ▍ 主要贡献 Key Contributions 一体化驱动单元设计

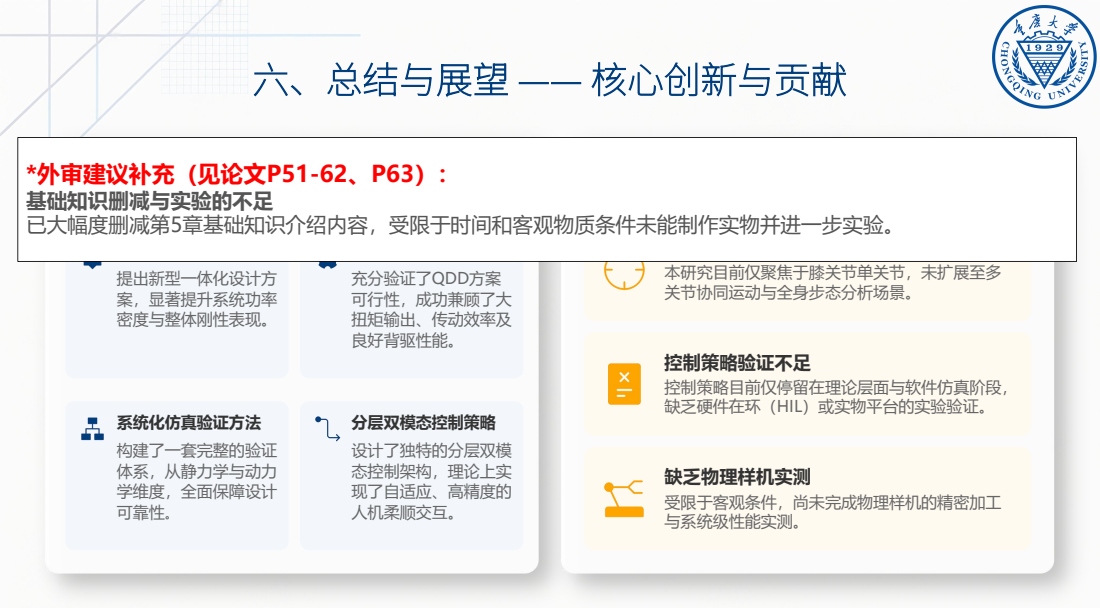
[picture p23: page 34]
提出新型一体化设计方 案，显著提升系统功率 密度与整体刚性表现。; 系统化仿真验证方法 构建了一套完整的验证 体系，从静力学与动力 学维度，全面保障设计; 可靠性。; 分层双模态控制策略; 设计了独特的分层双模 态控制架构，理论上实 现了自适应、高精度的 人机柔顺交互。; 研究范围受限 本研究目前仅聚焦于膝关节单关节，未扩展至多 关节协同运动与全身步态分析场景。 控制策略验证不足; 受限于客观条件，尚未完成物理样机的精密加工 与系统级性能实测。; *外审建议补充（见论文P51-62、P63）： 基础知识删减与实验的不足 已大幅度删减第5章基础知识介绍内容，受限于时间和客观物质条件未能制作实物并进一步实验。

▍ 研究局限性 Research Limitations

准直驱(QDD)的验证
充分验证了QDD方案
可行性，成功兼顾了大
扭矩输出、传动效率及
良好背驱性能。

控制策略目前仅停留在理论层面与软件仿真阶段，
缺乏硬件在环（HIL）或实物平台的实验验证。 缺乏物理样机实测

# 六、未来展望

# 本研究为外骨骼一体化关节驱动器的设计提供了一套系统化的方法论。

# 近期目标

### 建立联合仿真平台，

验证控制策略。 | 中期目标

### 扩展至多关节设计，

研究协同控制。 | 中远期目标

### 完成样机加工与测试，

对比仿真结果。 | 远期目标

### 开展临床康复试验， 推动工程化应用。

致 谢

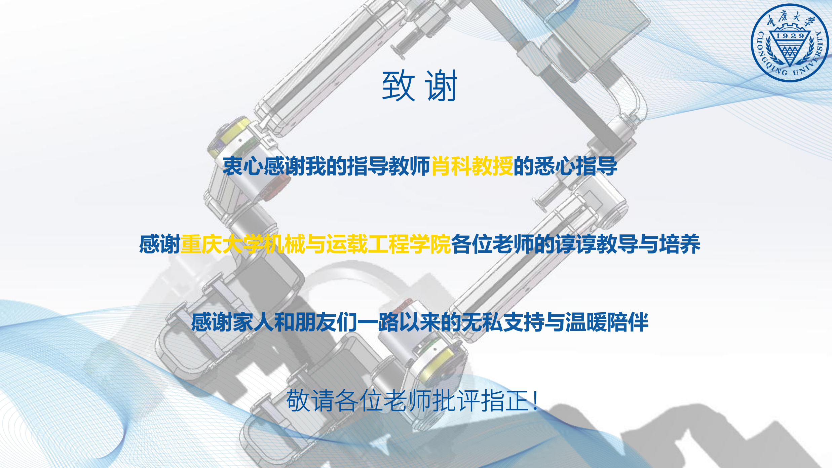
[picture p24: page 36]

# 衷心感谢我的指导教师肖科教授的悉心指导

# 感谢重庆大学机械与运载工程学院各位老师的谆谆教导与培养

# 感谢家人和朋友们一路以来的无私支持与温暖陪伴

# 敬请各位老师批评指正！

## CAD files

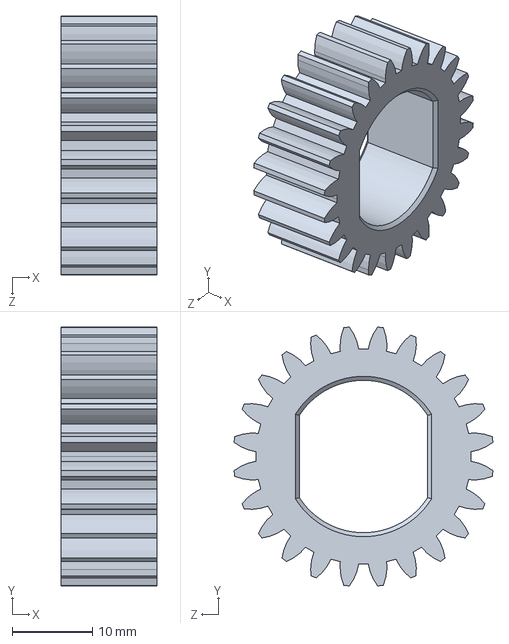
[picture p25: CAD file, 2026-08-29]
CAD/Drive-Unit/Parts/新太阳轮.SLDPRT
12.0 x 32.3 x 32.3 mm

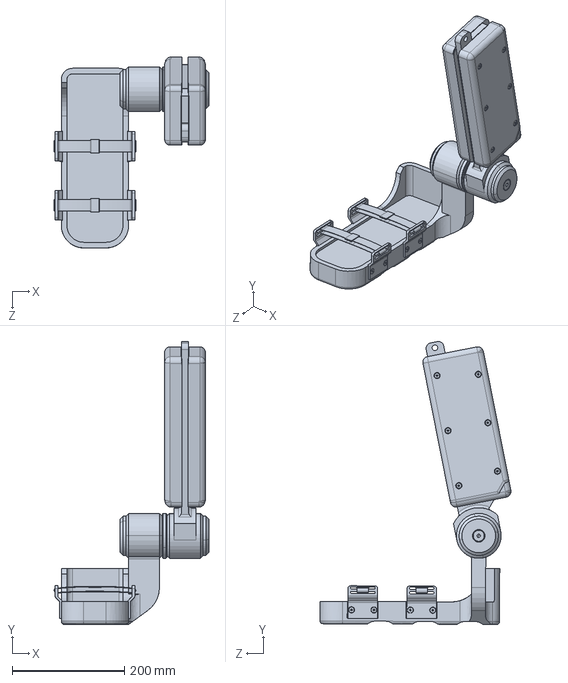
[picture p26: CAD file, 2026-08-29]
CAD/Exoskeleton-Integration/Parts/左小腿.SLDPRT
275.8 x 504.4 x 340.4 mm

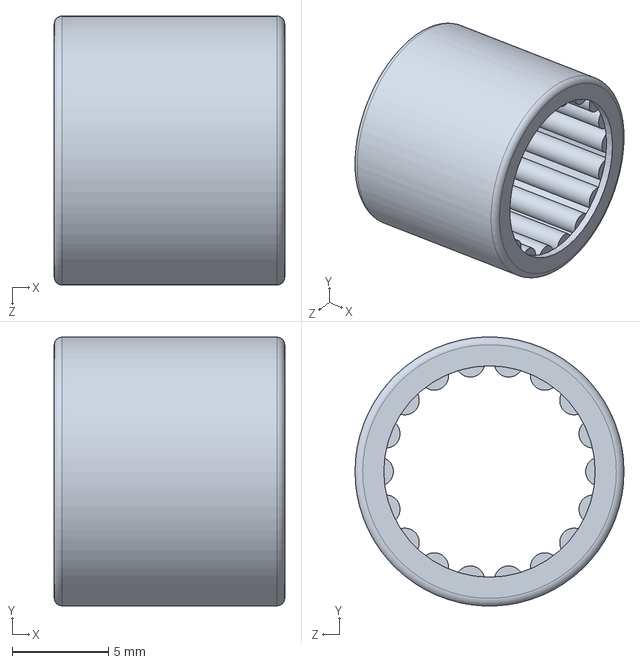
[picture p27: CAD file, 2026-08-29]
CAD/Planetary-Gearbox/Parts/滚针轴承HK 1012.SLDPRT
12.0 x 14.0 x 14.0 mm

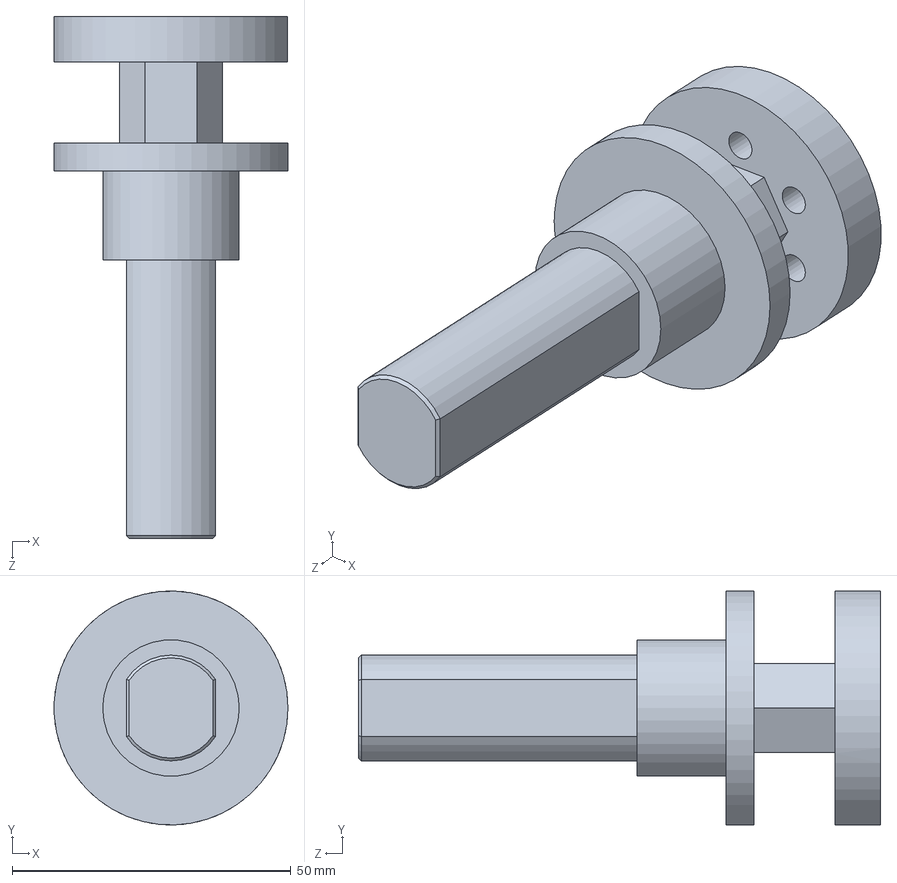
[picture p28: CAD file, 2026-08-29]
CAD/Drive-Unit/Parts/长轴.SLDPRT
42.0 x 42.0 x 93.7 mm

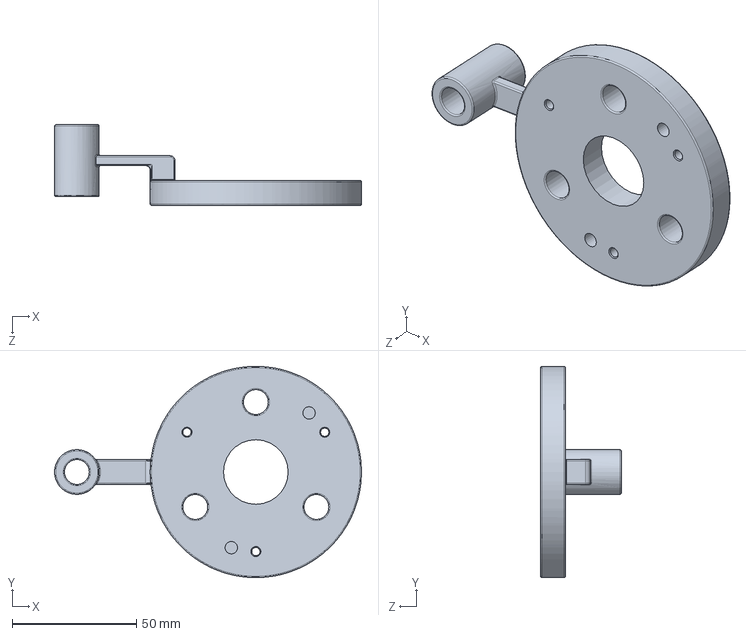
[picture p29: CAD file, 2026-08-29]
CAD/Planetary-Gearbox/Parts/Spider.SLDPRT
123.5 x 85.0 x 32.5 mm

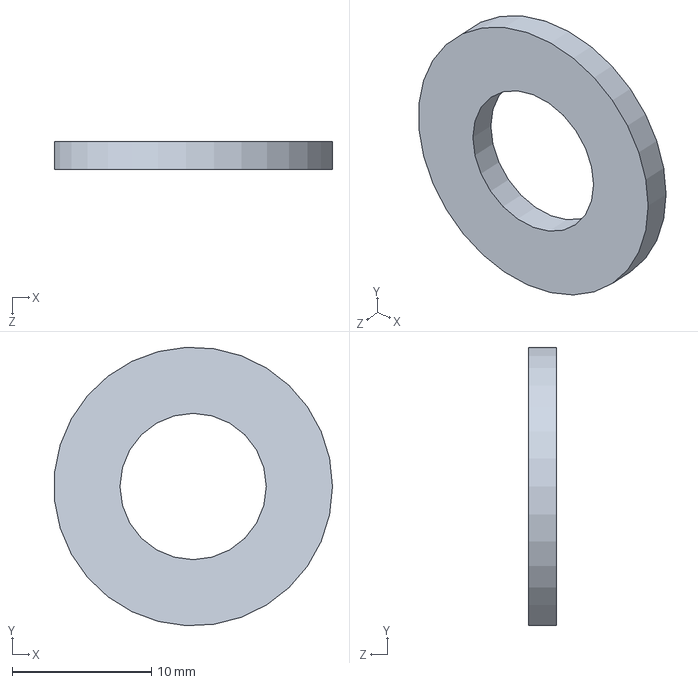
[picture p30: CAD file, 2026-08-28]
CAD/Planetary-Gearbox/Parts/调整垫片.SLDPRT
19.9 x 20.0 x 2.00 mm

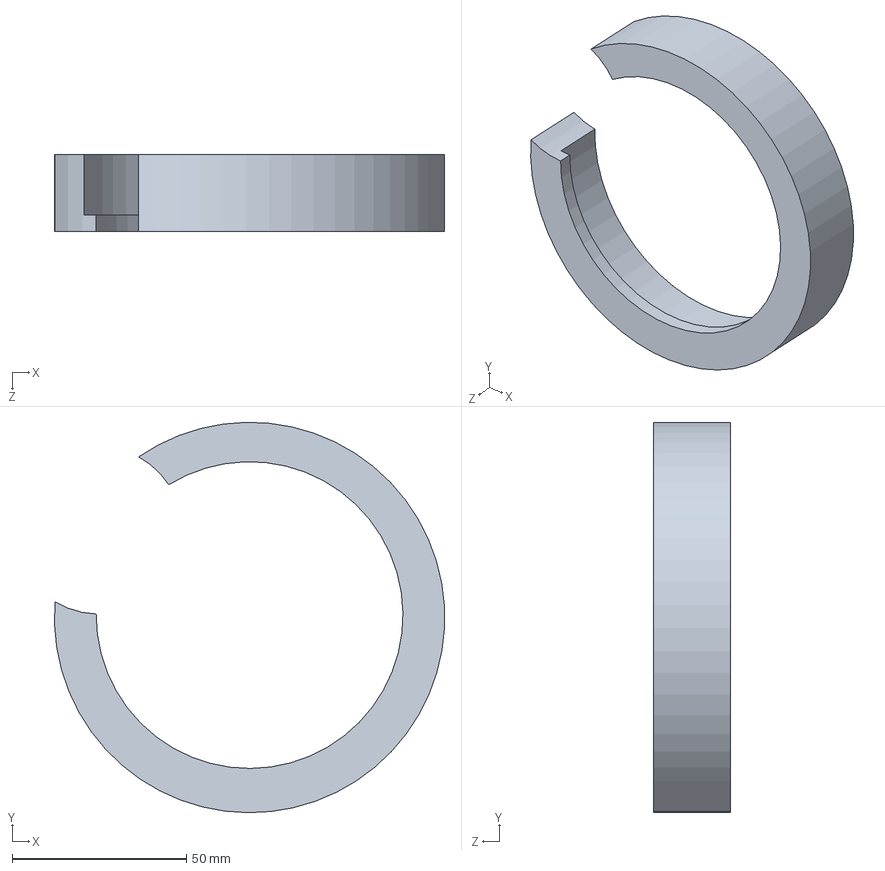
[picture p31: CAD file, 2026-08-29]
CAD/Drive-Unit/Parts/外壳2.SLDPRT
111.9 x 112.0 x 22.0 mm

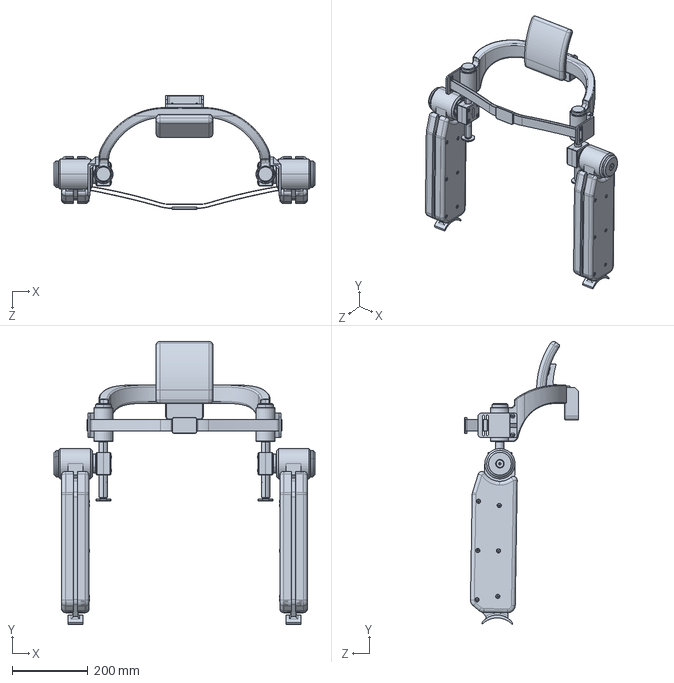
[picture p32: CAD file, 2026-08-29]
CAD/Exoskeleton-Integration/Parts/髋部+大腿.SLDPRT
687.9 x 746.7 x 300.9 mm

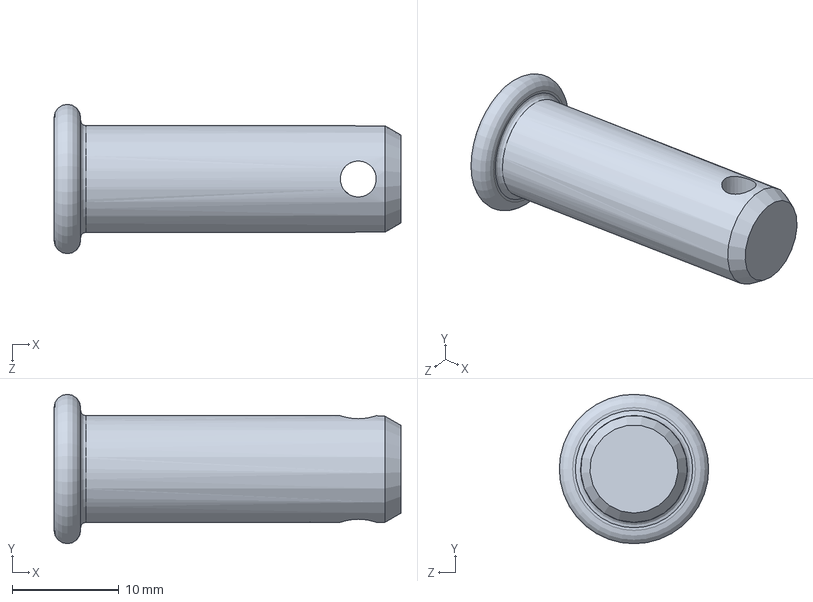
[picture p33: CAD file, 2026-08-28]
CAD/Planetary-Gearbox/Parts/销轴.SLDPRT
32.5 x 14.0 x 14.0 mm

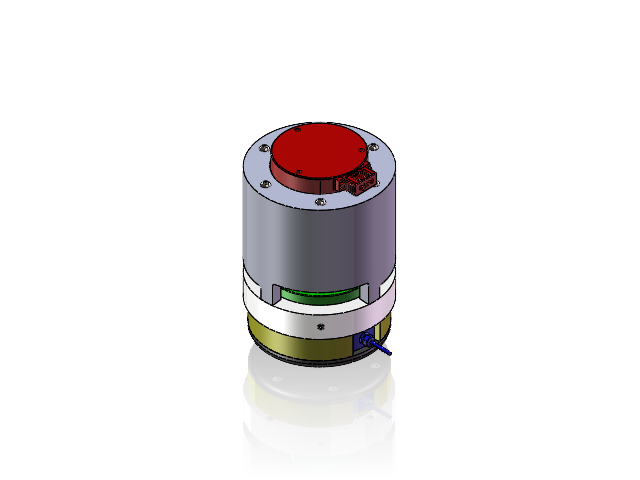
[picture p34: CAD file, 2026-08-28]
CAD/Drive-Unit/Assembly/驱动单元_新.SLDASM
MANIFOLD_SOLID_BREP_263.stp_1.STEP
MANIFOLD_SOLID_BREP_264.stp_1.STEP
MANIFOLD_SOLID_BREP_265.stp_1.STEP
MANIFOLD_SOLID_BREP_266.stp_1.STEP
MANIFOLD_SOLID_BREP_267.stp_1.STEP
MANIFOLD_SOLID_BREP_268.stp_1.STEP
MANIFOLD_SOLID_BREP_269.stp_1.STEP
MANIFOLD_SOLID_BREP_270.stp_1.STEP
MANIFOLD_SOLID_BREP_287.stp_1.STEP
AKA10-9-前机壳_1.STEP
AKA10-9-钢圈_1.STEP
AKA10-9-外壳_1.STEP
CRBT405A_1.STEP
AKA10-9-后机壳_1.STEP
AKA10-9压板_1.STEP
AKA10-9-盖板_1.STEP
C0207000185-母头护线套-A_1.STEP
长轴
spur gear_gb x 3
滚针轴承HK 1012 x 3
internal spur gear_gb
Spider
clevis pins with head gb x 3
plain washers-n series-grade a gb x 6
hexagon socket button head screws gb x 6
外壳1
外壳2
hex socket set screws with flat point gb x 3
hexagon socket head cap screws gb x 30
平面推力轴承AXK 2542
平面推力轴承AXK 2542的垫片 x 2
特征识别转子
新太阳轮
输出轴
parallel pins unhardening steel gb x 2
传感器transducer_fthg
固定盖
hex thin nuts-grades ab-chamfered gb x 6

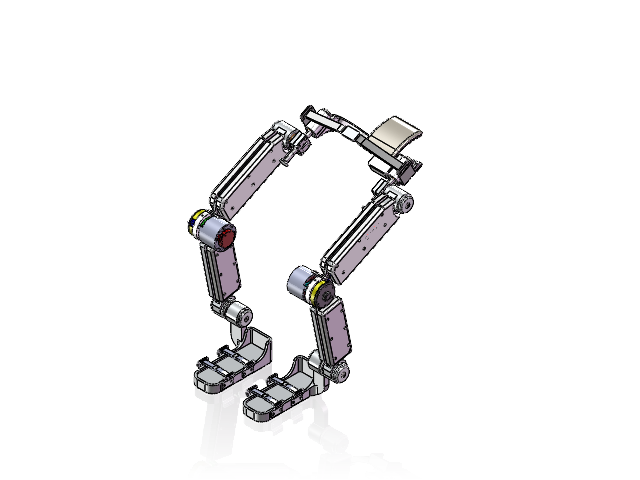
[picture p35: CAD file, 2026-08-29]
CAD/Exoskeleton-Integration/Assembly/装配体.SLDASM
右小腿
左小腿
髋部+大腿
MANIFOLD_SOLID_BREP_263.stp_1.STEP x 2
MANIFOLD_SOLID_BREP_264.stp_1.STEP x 2
MANIFOLD_SOLID_BREP_265.stp_1.STEP x 2
MANIFOLD_SOLID_BREP_266.stp_1.STEP x 2
MANIFOLD_SOLID_BREP_267.stp_1.STEP x 2
MANIFOLD_SOLID_BREP_268.stp_1.STEP x 2
MANIFOLD_SOLID_BREP_269.stp_1.STEP x 2
MANIFOLD_SOLID_BREP_270.stp_1.STEP x 2
MANIFOLD_SOLID_BREP_287.stp_1.STEP x 2
AKA10-9-前机壳_1.STEP x 2
AKA10-9-钢圈_1.STEP x 2
AKA10-9-外壳_1.STEP x 2
CRBT405A_1.STEP x 2
AKA10-9-后机壳_1.STEP x 2
AKA10-9压板_1.STEP x 2
AKA10-9-盖板_1.STEP x 2
C0207000185-母头护线套-A_1.STEP x 2
长轴 x 2
spur gear_gb x 6
滚针轴承HK 1012 x 6
internal spur gear_gb x 2
Spider x 2
clevis pins with head gb x 8
plain washers-n series-grade a gb x 12
hexagon socket button head screws gb x 12
外壳1 x 2
外壳2 x 2
hex socket set screws with flat point gb x 6
hexagon socket head cap screws gb x 72
平面推力轴承AXK 2542 x 2
平面推力轴承AXK 2542的垫片 x 4
特征识别转子 x 2
新太阳轮 x 2
输出轴 x 2
parallel pins unhardening steel gb x 4
传感器transducer_fthg x 2
固定盖 x 2
hex thin nuts-grades ab-chamfered gb x 12
circlips for shaft--type a large gb x 2

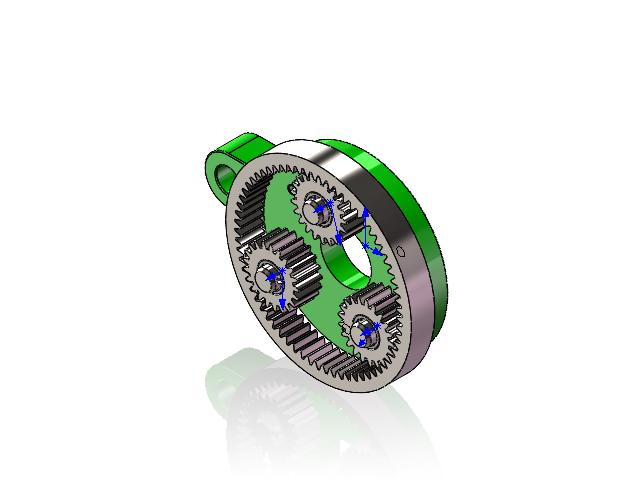
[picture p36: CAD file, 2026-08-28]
CAD/Planetary-Gearbox/Assembly/行星减速器.SLDASM
spur gear_gb x 3
滚针轴承HK 1012 x 3
internal spur gear_gb
Spider
clevis pins with head gb x 3
plain washers-n series-grade a gb x 6

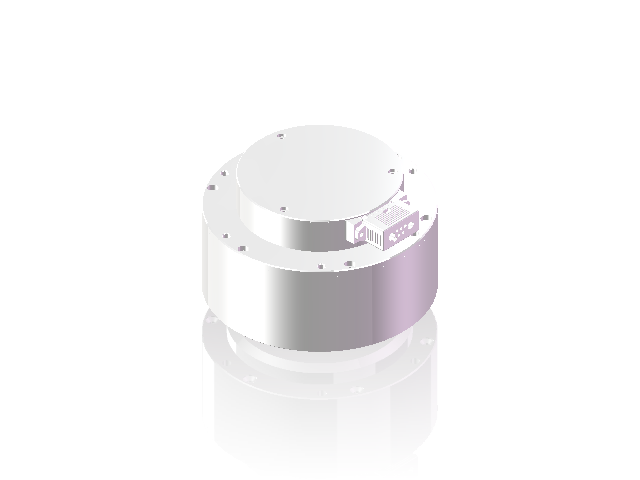
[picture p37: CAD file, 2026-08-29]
CAD/Drive-Unit/Parts/电机AKA10-9.SLDASM
MANIFOLD_SOLID_BREP_263.stp_1.STEP
MANIFOLD_SOLID_BREP_264.stp_1.STEP
MANIFOLD_SOLID_BREP_265.stp_1.STEP
MANIFOLD_SOLID_BREP_266.stp_1.STEP
MANIFOLD_SOLID_BREP_267.stp_1.STEP
MANIFOLD_SOLID_BREP_268.stp_1.STEP
MANIFOLD_SOLID_BREP_269.stp_1.STEP
MANIFOLD_SOLID_BREP_270.stp_1.STEP
MANIFOLD_SOLID_BREP_287.stp_1.STEP
AKA10-9-下行星架_1.STEP
AKA10-9-前机壳_1.STEP
AKA10-9-钢圈_1.STEP
AKA10-9-外壳_1.STEP
CRBT405A_1.STEP
AKA10-9-后机壳_1.STEP
AKA10-9压板_1.STEP
AKA10-9-盖板_1.STEP
C0207000185-母头护线套-A_1.STEP

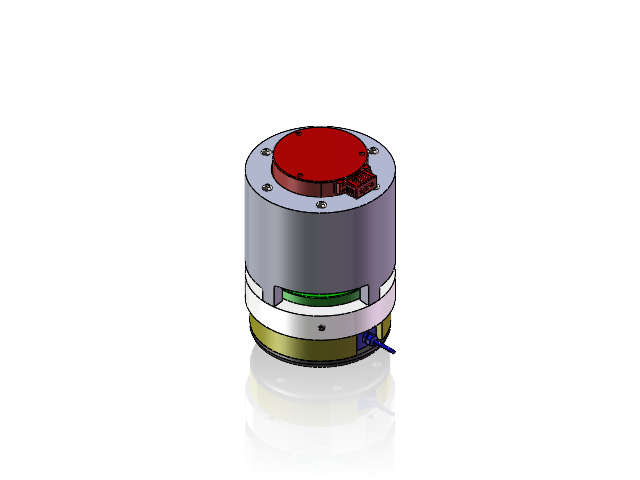
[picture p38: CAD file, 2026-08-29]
CAD/Exoskeleton-Integration/Parts/驱动单元_装配.SLDASM
MANIFOLD_SOLID_BREP_263.stp_1.STEP
MANIFOLD_SOLID_BREP_264.stp_1.STEP
MANIFOLD_SOLID_BREP_265.stp_1.STEP
MANIFOLD_SOLID_BREP_266.stp_1.STEP
MANIFOLD_SOLID_BREP_267.stp_1.STEP
MANIFOLD_SOLID_BREP_268.stp_1.STEP
MANIFOLD_SOLID_BREP_269.stp_1.STEP
MANIFOLD_SOLID_BREP_270.stp_1.STEP
MANIFOLD_SOLID_BREP_287.stp_1.STEP
AKA10-9-前机壳_1.STEP
AKA10-9-钢圈_1.STEP
AKA10-9-外壳_1.STEP
CRBT405A_1.STEP
AKA10-9-后机壳_1.STEP
AKA10-9压板_1.STEP
AKA10-9-盖板_1.STEP
C0207000185-母头护线套-A_1.STEP
长轴
spur gear_gb x 3
滚针轴承HK 1012 x 3
internal spur gear_gb
Spider
clevis pins with head gb x 3
plain washers-n series-grade a gb x 6
hexagon socket button head screws gb x 6
外壳1
外壳2
hex socket set screws with flat point gb x 3
hexagon socket head cap screws gb x 30
平面推力轴承AXK 2542
平面推力轴承AXK 2542的垫片 x 2
特征识别转子
新太阳轮
输出轴
parallel pins unhardening steel gb x 2
传感器transducer_fthg
固定盖
hex thin nuts-grades ab-chamfered gb x 6

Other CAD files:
CAD/Exoskeleton-Integration/Parts/Exoesqueleto.SLDASM
CAD/Drive-Unit/Parts/行星减速器.SLDASM
CAD/Drive-Unit/Parts/驱动单元.SLDASM
CAD/Exoskeleton-Integration/Parts/右小腿.SLDPRT
CAD/Drive-Unit/Parts/传感器transducer_fthg.SLDPRT
CAD/Drive-Unit/Parts/传感器和输出轴螺钉.SLDPRT
CAD/Drive-Unit/Parts/内齿圆和外壳螺钉.SLDPRT
CAD/Drive-Unit/Parts/固定盖.SLDPRT
CAD/Drive-Unit/Parts/固定盖和输出轴螺母.SLDPRT
CAD/Drive-Unit/Parts/固定盖和输出轴螺钉.SLDPRT
CAD/Drive-Unit/Parts/外壳1.SLDPRT
CAD/Drive-Unit/Parts/外壳1与外壳2螺钉.SLDPRT
CAD/Drive-Unit/Parts/外壳和电机螺钉.SLDPRT
CAD/Drive-Unit/Parts/平面推力轴承AXK 2542.SLDPRT
CAD/Drive-Unit/Parts/平面推力轴承AXK 2542的垫片.SLDPRT
CAD/Drive-Unit/Parts/法兰盘和长轴的键.SLDPRT
CAD/Drive-Unit/Parts/特征识别转子.SLDPRT
CAD/Drive-Unit/Parts/输出轴.SLDPRT
CAD/Drive-Unit/Parts/输出轴和行星架螺钉.SLDPRT
CAD/Drive-Unit/Parts/输出轴和行星架销钉.SLDPRT
CAD/Drive-Unit/Parts/长轴和电机螺钉.SLDPRT
CAD/Exoskeleton-Integration/Parts/大腿和驱动单元的螺钉.SLDPRT
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
